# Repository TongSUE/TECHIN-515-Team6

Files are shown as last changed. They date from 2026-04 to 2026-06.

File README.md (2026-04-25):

# AuraSync — Context-Aware Scent Diffuser

**AuraSync** automatically detects bathroom context (shower, odor, presence) via sensor fusion and triggers a fragrance diffuser at the right moment — no manual input required.

**Devlog:** [tongsue.github.io/TECHIN-515-Team6](https://tongsue.github.io/TECHIN-515-Team6/)  
**Course:** TECHIN 515 Hardware-Software Lab II, UW, Spring 2026  
**Team:** Yutong Luo (@TongSUE) · Lucia Shen (@xtshen777)

---

## Hardware

| Component | Role |
|---|---|
| Seeed XIAO ESP32-S3 | MCU — dual-core, 8 MB PSRAM, native I2S |
| Adafruit SPH0645LM4H | I2S MEMS microphone — voice recognition |
| HC-SR501 PIR | Presence detection — triggers actuation |
| Adafruit BME680 | Temp / humidity / pressure / VOC (I2C 0x77) |
| Ultrasonic atomizer + 2N2222 NPN | Fragrance mist actuation |
| MT3608 boost converter + 3.7 V LiPo | Power supply |

### Pin Assignments

| Function | Arduino Pin | GPIO |
|---|---|---|
| I2C SDA (BME680) | D4 | 5 |
| I2C SCL (BME680) | D5 | 6 |
| I2S BCLK (SPH0645) | D8 | 7 |
| I2S LRCLK (SPH0645) | D9 | 8 |
| I2S DOUT (SPH0645) | D10 | 9 |
| PIR signal (HC-SR501) | — | 4 |
| Atomizer MOSFET gate | — | 5 |
| Status LED | D0 | 21 |

> SPH0645: SEL pin → GND (left channel). Data in bits [31:14] of 32-bit I2S frame.  
> BME680: use `Wire.begin()` with no arguments — the framework maps D4/D5 by default.

---

## Repository Layout

```
Web/                          ← git root (this repo)
├── Code/
│   ├── AuraSync/             ← main firmware (two-layer state machine)
│   │   ├── AuraSync.ino
│   │   ├── partitions.csv    ← custom flash layout (app0 3.7 MB + model SPIFFS 4.25 MB)
│   │   └── secrets.h.example ← copy to secrets.h and fill in credentials
│   ├── VoiceTest/            ← ESP-SR voice recognition prototype
│   │   └── voice_monitor.html← Web Serial browser monitor
│   ├── FirebaseTest/         ← VoiceTest + Firebase Realtime Database
│   ├── MicTest/              ← SPH0645 bring-up / VAD test
│   ├── PIRTest/              ← PIR motion-triggered spray controller
│   └── PsramTest/            ← PSRAM validation
├── KiCAD/AuraSync_v1/        ← schematic + PCB layout (KiCAD 9)
├── monitor/
│   ├── voice_monitor.py      ← real-time serial monitor (USB, Streamlit)
│   ├── firebase_dashboard.py ← cloud dashboard (reads Firebase, no USB needed)
│   └── requirements.txt
├── web-devlog/               ← React + Vite devlog site
└── README.md
```

---

## Flashing AuraSync (Main Firmware)

1. Copy `Code/AuraSync/secrets.h.example` → `Code/AuraSync/secrets.h` and fill in your WiFi + Firebase credentials
2. Open `Code/AuraSync/AuraSync.ino` in Arduino IDE
3. **Tools → Board:** Seeed XIAO ESP32-S3
4. **Tools → PSRAM:** OPI PSRAM
5. **Tools → Partition Scheme:** Huge APP (3MB No OTA / 1MB SPIFFS)
6. Run `Code/VoiceTest/flash_model.ps1` **once** to write ESP-SR models to flash
7. Upload `AuraSync.ino`
8. Say **"Aura"** to open the 7-second command window, then **"Spray"** or **"Stop"**; PIR presence for ≥ 3 s also triggers spray

---

## Running the Serial Voice Monitor

Streams live audio level and recognised commands from the ESP32-S3 over USB serial.

**Requirements:** Python 3.9+, ESP32-S3 flashed with `VoiceTest.ino` or `AuraSync.ino`, Arduino IDE serial monitor **closed**.

```bash
cd monitor
pip install -r requirements.txt
streamlit run voice_monitor.py
```

Opens at `http://localhost:8501`. The app auto-detects the COM port — no configuration needed.

---

## Running the Firebase Cloud Dashboard

Reads spray events from Firebase Realtime Database — no USB connection required.

```bash
cd monitor
pip install -r requirements.txt
streamlit run firebase_dashboard.py
```

Opens at `http://localhost:8502`. Supports dark/light mode toggle; auto-refreshes every 5 seconds.

---

## Flashing VoiceTest (Voice Recognition Prototype)

1. Open `Code/VoiceTest/VoiceTest.ino` in Arduino IDE
2. **Tools → Board:** Seeed XIAO ESP32-S3
3. **Tools → PSRAM:** OPI PSRAM
4. **Tools → Partition Scheme:** Huge APP (3MB No OTA / 1MB SPIFFS)
5. Run `Code/VoiceTest/flash_model.ps1` **once** to write ESP-SR models to flash
6. Upload `VoiceTest.ino`
7. Say **"Aura"** to open the 7-second command window, then **"Spray"** or **"Stop"**

---

## Firmware Overview

### `Code/AuraSync/AuraSync.ino` — Main firmware (Week 4+)

Two-layer state machine, non-blocking (`millis()` only, no `delay()` in main loop):

**Layer 1 — System Mode** (PIR-driven presence):
```
MODE_SLEEP  ──PIR detected──▶  MODE_AWAKE
MODE_AWAKE  ──60 s no PIR──▶  MODE_SLEEP
```

**Layer 2 — Spray State** (shared absolute cooldown):
```
SPRAY_IDLE → SPRAY_SPRAYING (5 s) → SPRAY_COOLDOWN (20 s test / 3 min prod) → SPRAY_IDLE
```

Four-priority trigger model: P1 voice/app (bypasses cooldown, works in SLEEP) → P2 extreme VOC < 10 kΩ (works in SLEEP, queues during cooldown) → P3 PIR + VOC inflection (AWAKE + IDLE only).

FreeRTOS dual-core: I2S + ESP-SR on Core 1 at max priority; PIR, state machine, Firebase, BME680 on Core 0. Power saving: `WiFi.setSleep(WIFI_PS_MAX_MODEM)` + Core 0 throttle in SLEEP mode (~30 mA idle from 2000 mAh LiPo ≈ 60–70 h).

### `Code/VoiceTest/VoiceTest.ino` — Voice recognition prototype

ESP-SR AFE + MultiNet v7 on FreeRTOS Core 1. Wake-word state machine:

```
IDLE → (say "Aura") → LISTENING [7 s] → (say "Spray"/"Stop") → IDLE
```

### `Code/FirebaseTest/FirebaseTest.ino` — Voice + Firebase

Extends VoiceTest: SR task (Core 1) → FreeRTOS queue → `loop()` (Core 0) → `Firebase.RTDB.pushJSON()`. Auth via database-secret legacy token; NTP time sync at boot.

---

## Devlog Site

Built with React 19 + Vite. Auto-deployed to GitHub Pages.

```bash
cd web-devlog
npm install
npm run dev       # local preview
npm run build     # production build
```

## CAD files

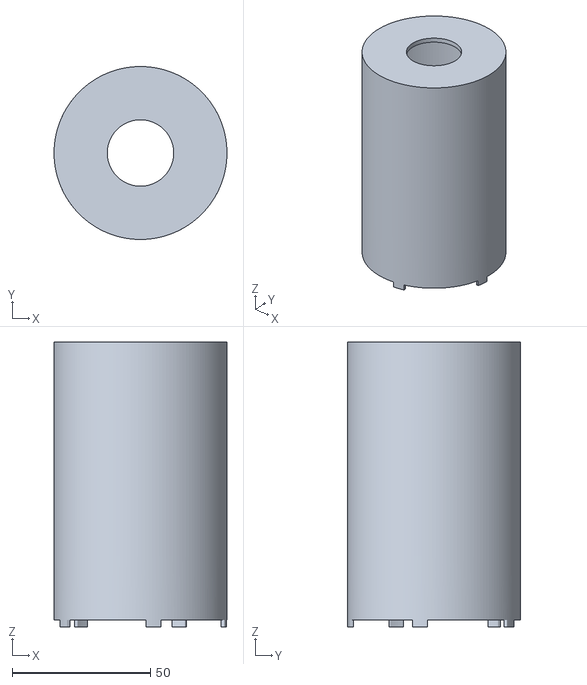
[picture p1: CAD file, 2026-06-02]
3D Model/inner body.stl
62.5 x 62.5 x 103.0

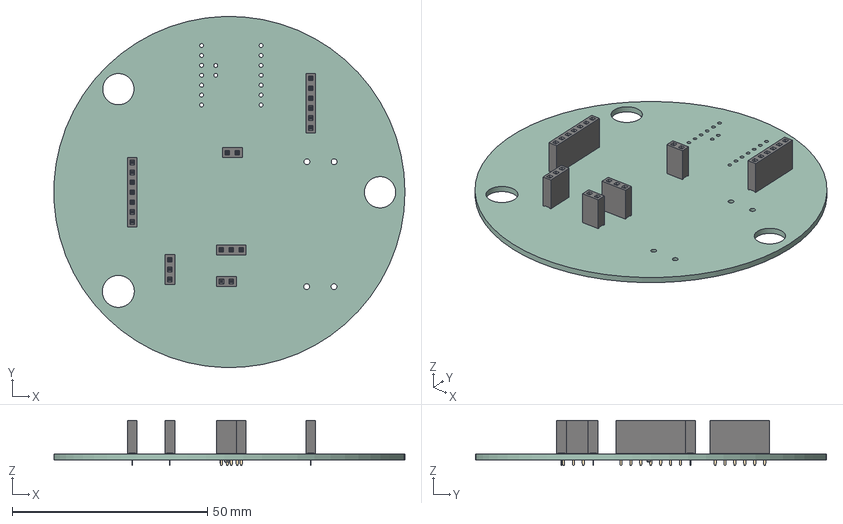
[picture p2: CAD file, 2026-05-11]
KiCAD/AuraSync_v2/AuraSync_v2.step
89.9 x 90.0 x 11.6 mm
PinSocket_1x02_P2.54mm_Vertical x 2
PinSocket_1x07_P2.54mm_Vertical
PinSocket_1x03_P2.54mm_Vertical x 2
PinSocket_1x06_P2.54mm_Vertical
R_0603_1608Metric
AuraSync_v2_PCB

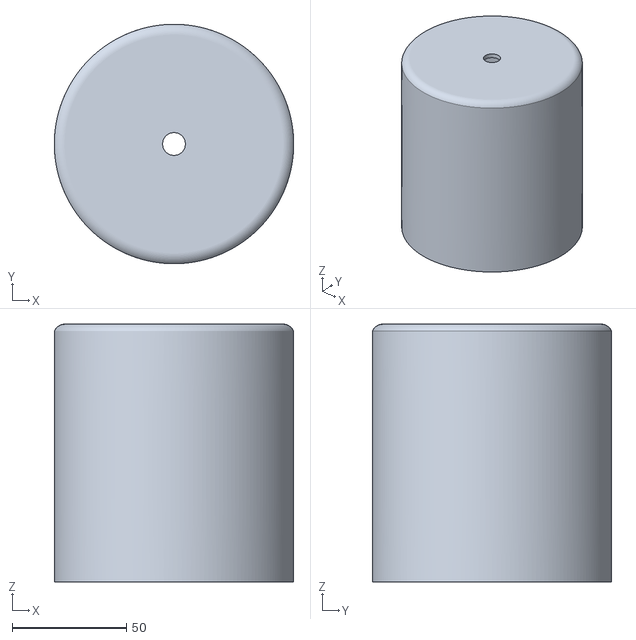
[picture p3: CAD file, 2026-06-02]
3D Model/upper body.stl
105.0 x 105.0 x 113.2

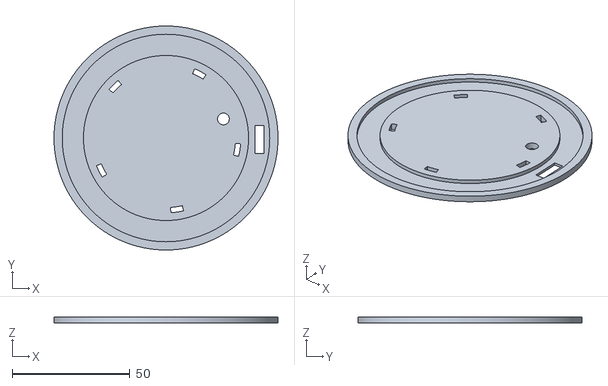
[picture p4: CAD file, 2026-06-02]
3D Model/platform stand.stl
95.0 x 95.0 x 2.50

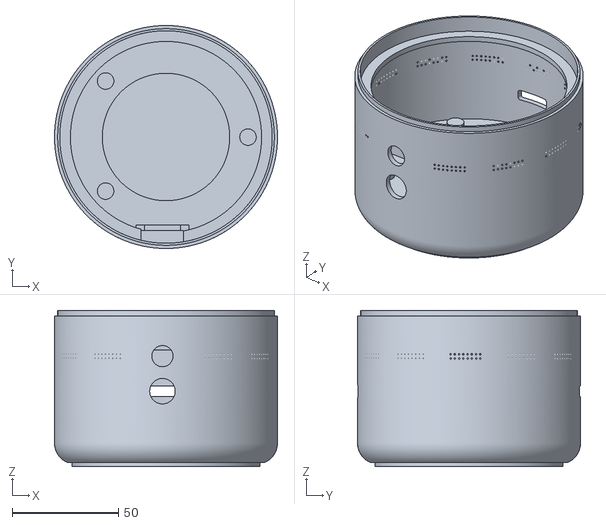
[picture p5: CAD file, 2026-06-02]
3D Model/lower body.stl
105.0 x 105.0 x 73.5

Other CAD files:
3D Model/aurasync.f3z

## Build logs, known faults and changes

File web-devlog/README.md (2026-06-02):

# AuraSync — TECHIN 515 Team 6

**AuraSync** is a context-aware bathroom scent diffuser built for MSTI Hardware–Software Lab II (TECHIN 515), Spring 2026. It senses shower, odor, and presence events using on-device sensor fusion and ML, then autonomously actuates an ultrasonic atomizer to dispense fragrance at the right moment.

Live devlog: [https://tongsue.github.io/TECHIN-515-Team6/](https://tongsue.github.io/TECHIN-515-Team6/)

---

## Team

| Member | GitHub | Focus |
|---|---|---|
| Yutong Luo | [@TongSUE](https://github.com/TongSUE) | Firmware · App · PCB · Devlog site |
| Lucia Shen | [@xtshen777](https://github.com/xtshen777) | Hardware · ML · CAD · Firmware |

---

## System Overview

### Hardware

| Component | Role |
|---|---|
| XIAO ESP32-S3 | Dual-core LX7 MCU, 8 MB flash, PSRAM |
| BME680 | Temperature / humidity / pressure / VOC gas resistance |
| INMP441 | I²S MEMS microphone (right channel, 16 kHz) |
| WS2812B × 24 | State-reactive LED ring (FastLED, GPIO3) |
| Ultrasonic atomizer | N-channel MOSFET drive on GPIO4 |
| Custom PCB | Circular R = 45 mm, JST connectors, MT3608 boost |
| LiPo 3.7 V | Battery via MT3608 → 5 V supply rail |

### Firmware

Built with **PlatformIO** (pioarduino, ESP-IDF 5.x). Key subsystems:

- **Two-layer state machine** — outer SLEEP/AWAKE, inner IDLE/SPRAYING/COOLDOWN
- **BSEC2** — self-calibrating IAQ index from BME680 via Bosch library
- **ESP-SR MultiNet7** — on-device wake-word + command recognition (`aura` / `spray` / `release` / `stop` / `fragrance`)
- **On-device ML** — IAQ MLP + Shower 1D-CNN infer from a 120-entry ring buffer (no cloud step)
- **Firebase RTDB** — bidirectional sync: app → ESP32 commands; ESP32 → app sensor data / status
- **DEMO\_MODE** — fast 3 s sampling, 30 s warmup, relaxed thresholds for classroom demos

### Five Trigger Paths

| # | Trigger | Mechanism |
|---|---|---|
| 1 | Voice | MultiNet7 detects "spray" or "release" keyword |
| 2 | App | Firebase command executed from any device state |
| 3 | IAQ Poor | On-device MLP classifies air quality as Poor |
| 4 | Shower CNN | 1D-CNN probability exceeds 0.65 |
| 5 | VOC + PIR | VOC inflection detected → PIR fires within 60 s |

Paths 3–5 are gated by the `autoSprayEnabled` flag from the app.

### LED Ring States

| State | Animation |
|---|---|
| Sleep | Slow blue breathing |
| IAQ Good / Moderate / Poor | Green / yellow / orange breathing |
| Spraying | White rotating chase |
| Cooldown | Cyan fade-out |
| Voice window | Purple double-flash |

### Mobile App

React Native (Expo SDK 54) + Firebase JS SDK 10. Features: live Air Quality card, spray history log, Auto-Spray toggle, reservoir tracker with reset, dual Firebase / ESP32 online status indicator.

### ML Pipeline

| Model | Input | Output | Performance |
|---|---|---|---|
| IAQ MLP (64→32→3) | 10 BSEC2 features | Good / Moderate / Poor | CV Macro F1 variance ±0.012 |
| Shower 1D-CNN | 30×6 normalised window | Shower probability | Val F1 0.902, AUC 0.94 |

Trained on 16 927 labelled bathroom readings; weights exported as C float arrays and inferred entirely on-chip.

---

## Devlog Site

Built with **React 19 + Vite 8 + Tailwind CSS 4**. Each week is a Markdown file with YAML front matter. Supports English / Chinese locale switching.

```
web-devlog/
├── public/images/devlog/       # Photos and figures
├── src/
│   ├── components/             # React UI components
│   ├── content/devlog/         # week-NN.md / week-NN.zh.md
│   ├── pages/                  # DevlogWeekPage, HomePage
│   └── i18n/strings.js         # EN/ZH UI strings + homepage credits
└── .github/workflows/          # GitHub Pages deploy
```

### Local development

```bash
cd web-devlog
npm install
npm run dev        # http://localhost:5173
```

Deployed automatically to GitHub Pages on every push to `main`.

---

MSTI Hardware–Software Lab II · Team 6 · Spring 2026

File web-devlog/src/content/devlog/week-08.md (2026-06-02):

---
week: 8
date: "May 19 - May 25, 2026"
title: "Enclosure Finishing, PCB Bring-up, LED Ring & Full Assembly"
status: "In Progress"
show_next_steps: true
summary: >
  The final build sprint. Yutong SLA-printed and wet-sanded the lower base
  (60 → 1000 grit, water-cooled), then trimmed, drilled, and accidentally
  cracked the clear resin lid — the team chose same-resin repair over recasting;
  Lucia prepared a fresh mold as backup; the repair finished cleaner than
  expected. The custom PCB arrived: Yutong soldered all components and wired
  the 24-LED WS2812B ring. Lucia integrated five state-reactive LED animations,
  migrated the build to PlatformIO (ESP-IDF 5.x), and tuned voice recognition
  — adding "Release" as a second trigger word after "Spray" proved unreliable
  in noisy environments. Final assembly confirmed all five trigger paths
  working end-to-end.
credits:
  - name: Lucia
    initials: L
    tags:
      - LED Firmware
      - Voice Tuning
      - Resin Lid Re-mold (backup)
      - Full Assembly
      - Final Presentation Slides
  - name: Yutong
    initials: Y
    tags:
      - PCB Soldering
      - Enclosure Finishing
      - Resin Lid Repair
      - Full Assembly
      - Devlog
prior_week_progress:
  sand-cover: true
  print-base: true
  full-assembly: true
  pcb-soldering: true
  backup-video: "partial"
planned_next:
  - id: backup-video
    label: Record Backup Demo Video
    description: "Record a complete run-through of all five trigger paths as a fallback in case the live demo has connectivity or environmental issues."
  - id: final-demo
    label: Final Project Demo
    description: "Present AuraSync at the final demo session — device, app, and Firebase all operational; all five trigger paths ready."
---

## Executive Summary

Four tracks this week brought the project to completion.

- **Enclosure** — Both halves finished. Yutong SLA-printed and wet-sanded the lower base (60 → 1000 grit, water-cooled) with Kevin's guidance. The resin upper lid was trimmed with a band saw, then drilled for the spray nozzle — the resin cracked. After consulting Kevin, the team chose same-resin repair over recasting; Lucia prepared a backup mold in parallel. The repair was unexpectedly clean; both halves were re-sanded together to a uniform frosted finish.
- **PCB & Electronics** — The custom PCB arrived. Yutong soldered all breakout connectors, the atomizer MOSFET, MT3608, and WS2812B ring leads. Several debugging passes cleared short circuits before bring-up was clean.
- **Firmware** — Lucia integrated five state-reactive WS2812B animations and migrated the build to PlatformIO (ESP-IDF 5.x). Voice recognition was tuned after "Spray" proved unreliable in ambient noise — "Release" was added as a second trigger word.
- **Full Assembly** — All components seated in the enclosure. All five trigger paths verified end-to-end. The app → Firebase → ESP32 pipeline and LED ring are both operational.

## 1. Enclosure — Final Finishing

### Lower Base — SLA Print & Sanding

With the SLA printer repaired, Yutong printed the lower base resin with Kevin's guidance. Post-print finishing:

1. Remove support structures
2. UV post-cure (secondary hardening pass)
3. Wet-sand: 60 → 120 → 240 → 400 → 600 → 1000 grit

> **Wet-sanding tip:** Keeping the sandpaper dipped in water throughout each grit stage dissipates heat — preventing the resin from micro-melting and clogging the abrasive — and eliminates resin dust becoming airborne. The water turns visibly cloudy as it lifts the material instead.

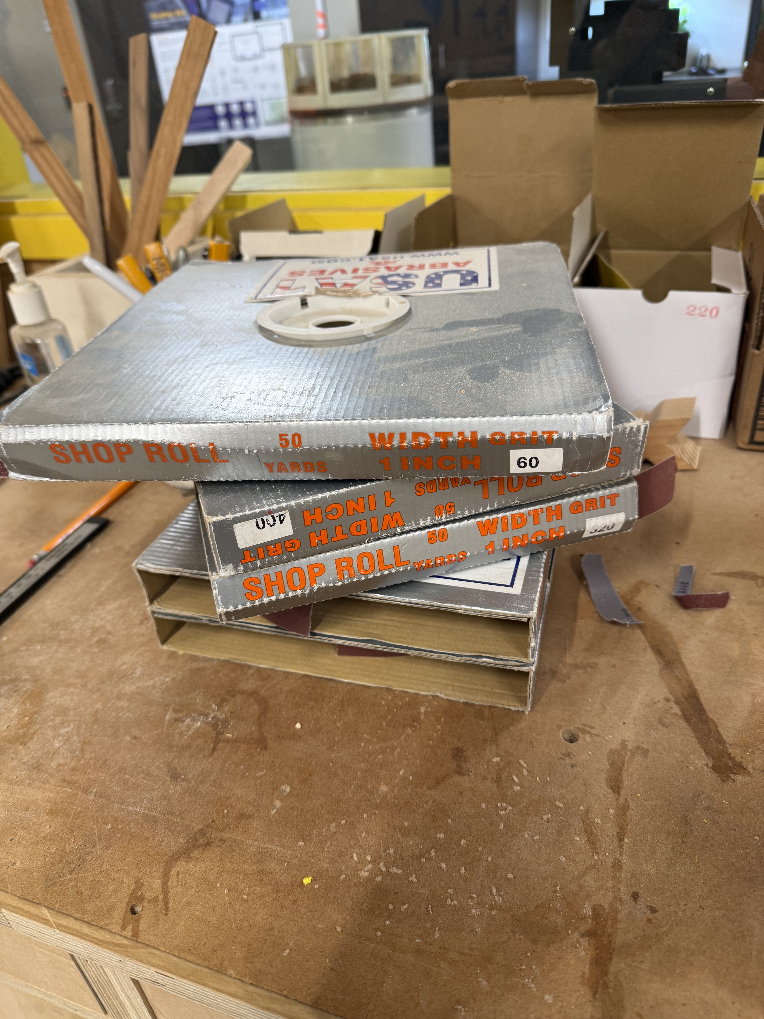
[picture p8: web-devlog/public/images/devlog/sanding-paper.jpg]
Wet sanding the lower base — sandpaper dipped in water at each grit stage Wet sanding — water keeps the paper clear and prevents heat build-up


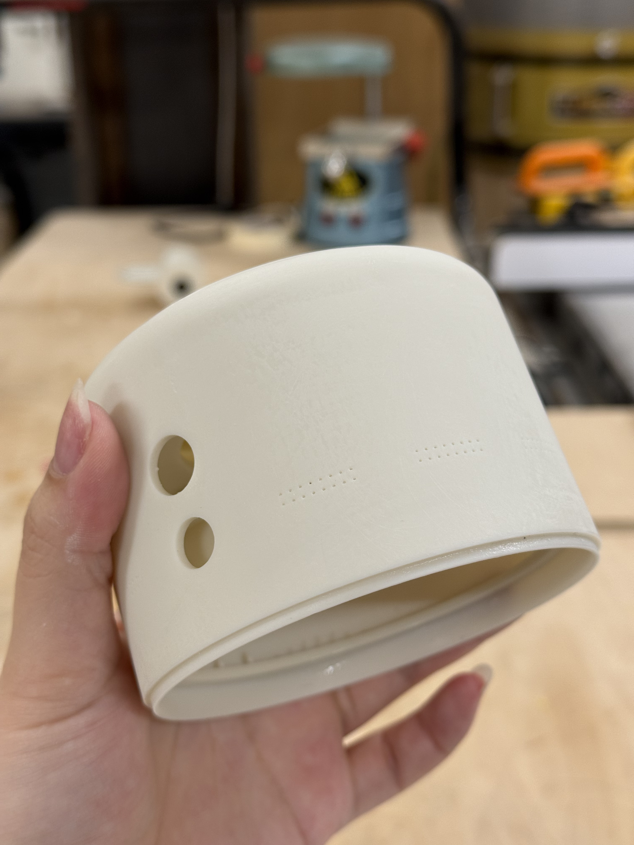
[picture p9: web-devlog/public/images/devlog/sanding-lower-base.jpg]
Finished lower base after SLA printing and wet sanding to 1000 grit Finished lower base — smooth resin surface ready for assembly


### Transparent Upper Lid — Trim, Drill & Repair

The cast resin lid needed two finishing steps: trim excess flash from the perimeter and drill the spray nozzle opening at the apex.

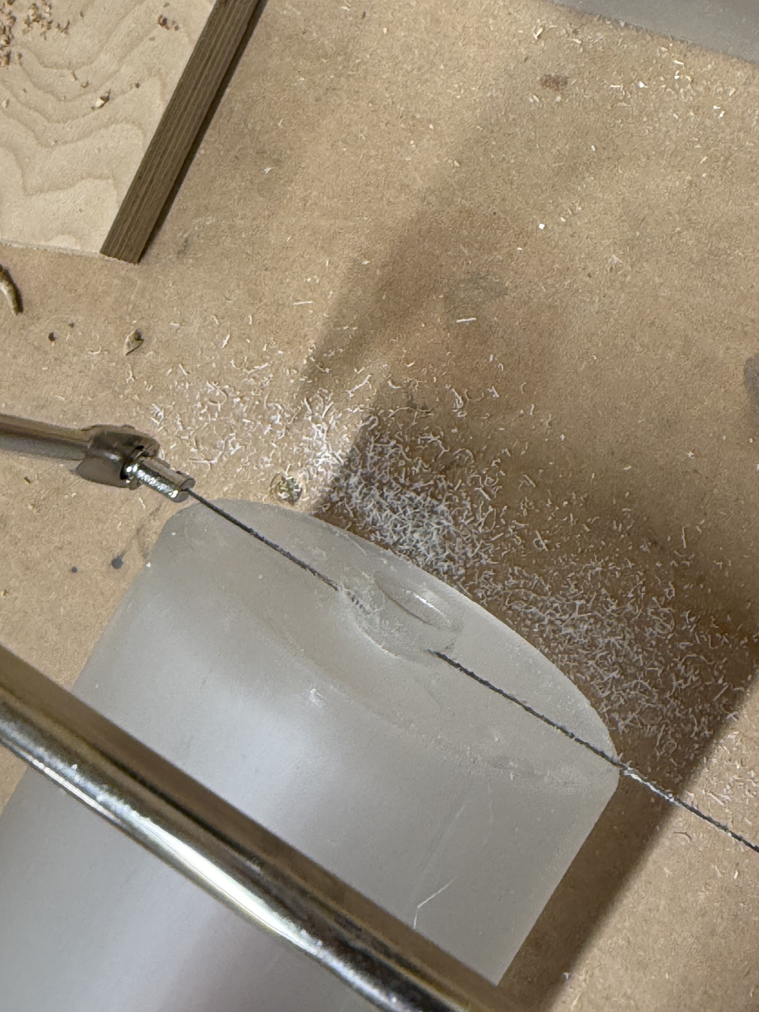
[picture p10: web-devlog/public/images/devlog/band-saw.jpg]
Trimming excess resin flash from the lid perimeter with a band saw Band saw trim — removing excess flash before drilling the nozzle hole


After trimming, the spray hole was drilled at the top centre. When the drill broke through, the resin cracked radially outward from the hole.

Kevin was consulted. Three options were considered:

| Option | Pros | Cons |
|---|---|---|
| Recast | Guaranteed clean result | 48+ h cure; lose the finished piece |
| UV glue repair | Fast (minutes) | Different material; may leave a visible seam |
| Same-resin repair | Material match; strong, near-invisible bond | 24 h cure; cosmetic result uncertain |

> **Why same-resin?** Using the identical material means the fill bonds chemically with the surrounding piece rather than just adhering to the surface — the seam becomes structurally continuous. After sanding, the colour, translucency, and surface texture match the original almost perfectly. In parallel, Lucia re-modelled and prepared a fresh silicone mold as a backup in case the repair failed — it turned out not to be needed.

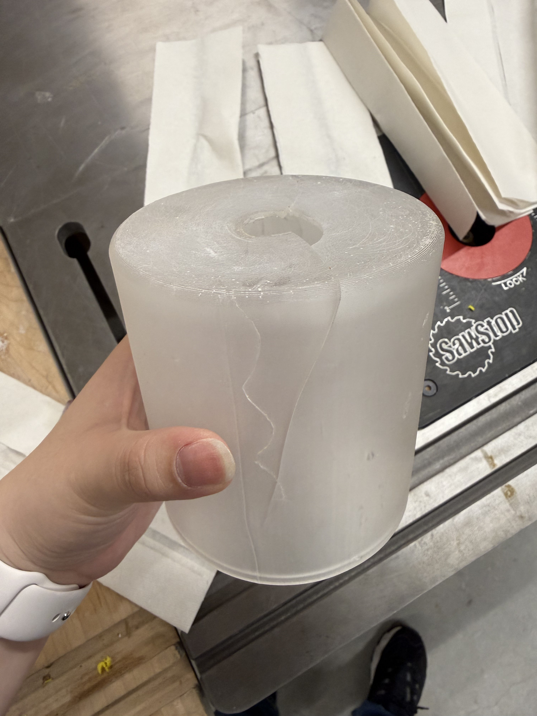
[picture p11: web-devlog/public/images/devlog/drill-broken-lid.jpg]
Resin upper lid with radial cracks from the drilled spray nozzle opening Drill-through crack — resin cracked radially from the nozzle hole


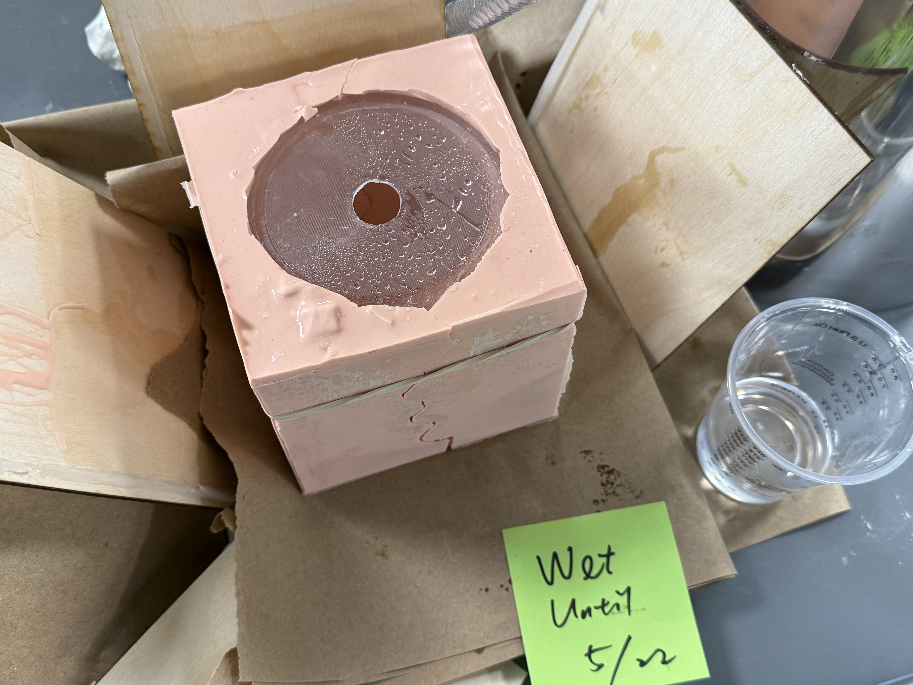
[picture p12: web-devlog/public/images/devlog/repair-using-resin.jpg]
Same-resin repair — liquid resin worked into cracks before 24 h cure Same-resin repair — liquid resin fills the cracks; 24 h cure


After curing, Lucia and Yutong re-sanded the lid together.

> The repair was cleaner than the team expected — after re-sanding, the crack lines are nearly invisible and the frosted finish is consistent across the whole surface.

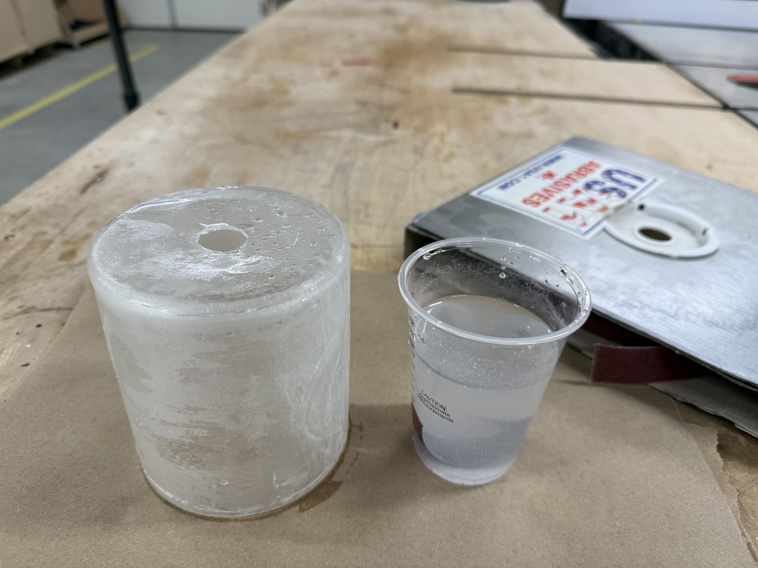
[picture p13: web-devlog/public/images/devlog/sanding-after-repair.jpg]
Re-sanding the repaired lid — Lucia and Yutong finishing together Post-repair sanding — crack lines nearly invisible after re-sand


## 2. PCB & Electronics

The custom PCB arrived this week. Yutong soldered all components onto the board:

- JST connector headers — ESP32-S3, BME680, PIR, INMP441
- MOSFET + gate resistor for the atomizer drive circuit
- MT3608 boost converter pads
- 24-LED WS2812B ring lead wires to GPIO3 (D2)

Multiple debugging passes identified and cleared short circuits before the board passed bring-up cleanly.

## 3. Firmware — LED Ring & Voice

### WS2812B LED Ring

Lucia integrated a 24-LED WS2812B ring (FastLED 3.9.0, GPIO3) with five state-reactive animations that give AuraSync a clear visual language for every state:

| Device state | Animation |
|---|---|
| Sleep | Slow blue breathing |
| IAQ Good / Moderate / Poor | Green / yellow / orange breathing |
| Spraying | White rotating chase (3–4 pixels, 30 ms/step) |
| Cooldown | Cyan fade-out |
| Voice trigger window | Purple double-flash |

Frame rate capped at ~60 fps via `millis()` delta (16 ms per tick).

### PlatformIO Migration

The build was migrated from Arduino IDE (ESP-IDF 4.x) to **PlatformIO** (pioarduino, ESP-IDF 5.x). FastLED 3.9.0 is now pinned, builds are reproducible, and compiler diagnostics are much cleaner.

### Voice Command Tuning

After full assembly, voice recognition was tested in real conditions. The results were mixed:

- **"Aura"** (wake) and **"Stop"** (cancel) — reliable
- **"Spray"** — consistently missed in ambient noise

> **Why "Spray" fails and "Release" works:** "Spray" opens with a sibilant /spr/ cluster — a high-frequency blend that the acoustic cavity significantly attenuates. "Release" has a liquid-consonant onset and an open vowel, making it far more robust in a noisy room. Both words now map to the same spray action; the system effectively gained a more reliable trigger word for free.

Fix: **"Release"** was added as a second trigger word with the MultiNet7 threshold at `0.45f`. Active voice commands: `aura` / `spray` / `fragrance` / `release` / `stop`

## 4. Full Assembly & Integration

All components were seated into the assembled enclosure. All five trigger paths confirmed to fire correctly:

1. **Voice** — "Aura" wake + "Release" / "Spray" triggers spray via priority queue
2. **App** — Firebase command received and executed from any state, including SLEEP
3. **IAQ Poor** — on-device MLP classifies air quality as Poor; triggers spray (gated by `autoSprayEnabled`)
4. **Shower CNN** — 1D-CNN probability exceeds threshold; transitions to SPRAYING (gated by `autoSprayEnabled`)
5. **VOC inflection + PIR (P3)** — latch: inflection detected → PIR fires within 60 s → spray (gated by `autoSprayEnabled`)

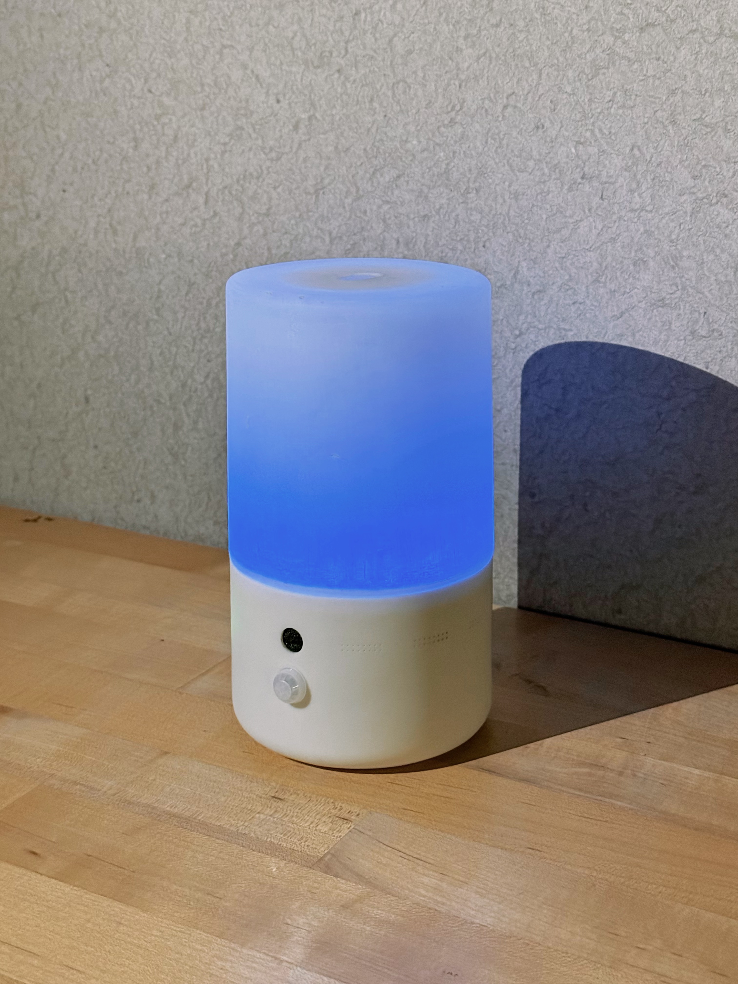
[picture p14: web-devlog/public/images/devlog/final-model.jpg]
AuraSync fully assembled — transparent frosted upper lid over resin lower base, all components seated Final assembly — both halves closed, all components inside


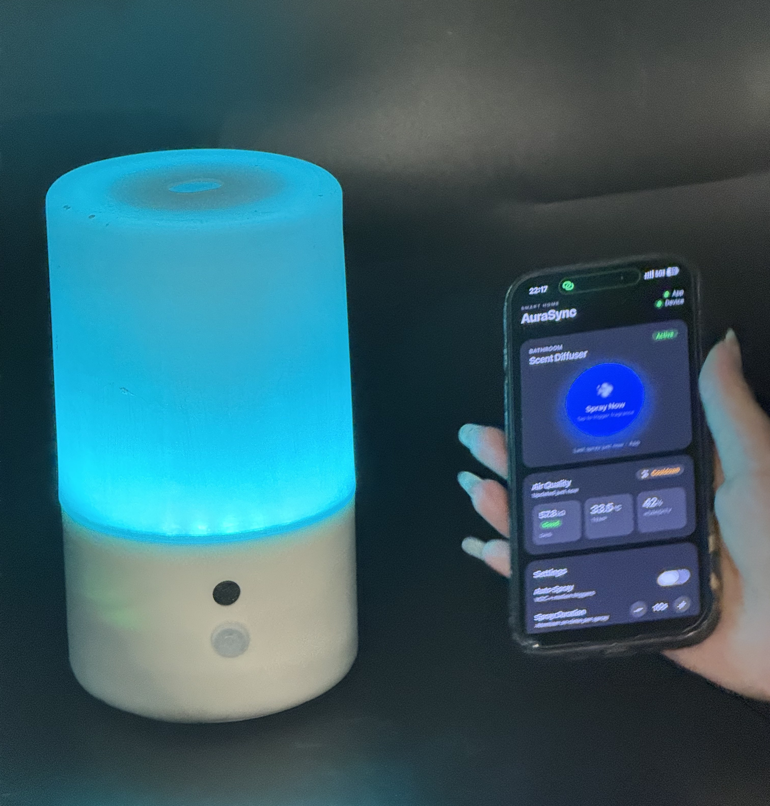
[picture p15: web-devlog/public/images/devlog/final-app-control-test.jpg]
App trigger test — spray command sent via Firebase, ESP32 responds in real time App trigger — Firebase → ESP32 in ~1 s


### Demo Footage

Raw footage of all five trigger paths was captured during integration testing this week. The clips are not yet edited or polished enough for a formal submission — a proper re-record with clean takes and narration is planned for next week.

## Next Steps

| Done | Task | Description |
|:-:|---|---|
| <input type="checkbox" /> | **Record Backup Demo Video** | Re-record all five trigger paths with clean takes; edit into a submission-ready demo video. |
| <input type="checkbox" /> | **Final Project Demo** | Present AuraSync — device, app, and Firebase all operational; all five trigger paths ready. |

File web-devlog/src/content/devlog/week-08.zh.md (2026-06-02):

---
week: 8
date: "2026年5月19日 - 5月25日"
title: "外壳收尾、PCB 焊接、灯带固件与整机组装"
status: "In Progress"
show_next_steps: true
summary: >
  最后的冲刺。Yutong 在 Kevin 的帮助下 SLA 打印了下底座并湿磨至
  1000 目；随后用条锯修整、钻孔打开雾化口——树脂裂开了。团队咨询
  Kevin 后选择用同款树脂填补裂缝，Lucia 同步重新建模做了备用翻模模具，
  最终修补效果出乎意料地好。定制 PCB 到货，Yutong 完成了全部元件及
  WS2812B 灯带的焊接。Lucia 集成了五种状态响应式灯带动画，将构建
  系统迁移至 PlatformIO（ESP-IDF 5.x），并对语音识别进行了调优——
  新增"Release"作为"Spray"的替代触发词。整机组装后五条触发路径
  全部验证通过。
credits:
  - name: Lucia
    initials: L
    tags:
      - LED 灯带固件
      - 语音调优
      - 树脂上盖翻模（备用）
      - 整机组装
      - 最终演示幻灯片
  - name: Yutong
    initials: Y
    tags:
      - PCB 焊接
      - 外壳收尾
      - 树脂上盖修补
      - 整机组装
      - 开发日志
prior_week_progress:
  sand-cover: true
  print-base: true
  full-assembly: true
  pcb-soldering: true
  backup-video: "partial"
planned_next:
  - id: backup-video
    label: 录制备用演示视频
    description: "重新录制五条触发路径的完整演示，剪辑为正式提交版本，以备现场演示出现网络或环境问题时使用。"
  - id: final-demo
    label: 最终演示
    description: "在结课演示中展示 AuraSync——设备、应用与 Firebase 全部就绪，五条触发路径均可演示。"
---

## 执行摘要

本周四条主线，项目完成收官。

- **外壳** — 上下两半全部完工。Yutong 在 Kevin 指导下打印并湿磨好了下底座（60 → 1000 目，水冷打磨）；透明上盖用条锯裁边后钻雾化口，钻穿时树脂从孔缘向外放射状开裂。咨询 Kevin 后选择同款树脂填补，Lucia 同步重新建模备用翻模模具。修补效果惊人地干净，两人共同打磨后裂缝几乎不可见。
- **PCB 与电路** — 定制 PCB 到货。Yutong 完成了所有元件及 WS2812B 灯带的焊接，经多轮调试排除短路后成功上电。
- **固件** — Lucia 集成了五种状态响应式 WS2812B 灯带动画，将构建系统迁移至 PlatformIO（ESP-IDF 5.x）。在真实环境中测试后发现"Spray"识别率较差，新增"Release"作为第二触发词，识别效果显著改善。
- **整机组装** — 全部组件装入外壳，五条触发路径逐一验证通过。应用 → Firebase → ESP32 喷雾链路稳定可靠，灯带状态反馈清晰。

## 1. 外壳——最终收尾

### 下底座——SLA 打印与打磨

打印机修好后，Yutong 在 Kevin 的指导下完成了下底座树脂打印。打印后处理流程：

1. 去除支撑结构
2. UV 二次固化
3. 湿磨：60 → 120 → 240 → 400 → 600 → 1000 目

> **湿磨技巧：** 砂纸全程浸水，既能散热——防止树脂因摩擦微熔堵塞砂粒——又能将粉尘锁在水中，避免扬尘。水变浑浊正是材料被带走的信号，比干磨效率更高。

湿磨下底座——砂纸在每个目数阶段均浸水打磨 湿磨——水分保持砂纸清洁，防止发热

打磨完成的下底座——SLA 打印、UV 固化并湿磨至 1000 目 完成后的下底座——树脂表面光洁，可以装配

### 透明上盖——裁切、钻孔与修补

翻模完成的树脂上盖需要两步收尾：用条锯裁去多余边缘，再在顶部钻出雾化口。

用条锯裁切上盖多余边缘 条锯修边——裁去多余树脂后再钻孔

裁边完成后，在顶部中心钻雾化口。钻头钻穿瞬间，树脂从孔缘向外放射状开裂。

咨询 Kevin 后，团队综合评估了三种方案：

| 方案 | 优点 | 缺点 |
|---|---|---|
| 重新翻模 | 效果有保障 | 固化 48 小时以上；成品报废 |
| UV 胶修补 | 快速（数分钟） | 材料不同，可能留下可见痕迹 |
| 同款树脂修补 | 材质匹配，粘合牢固，几乎不留痕 | 需固化 24 小时；外观效果存在不确定性 |

> **为什么选同款树脂？** 使用相同材料填补，树脂与周围结构形成化学键合而非单纯的表面粘附——接缝从结构上变为一体。打磨后颜色、透明度与表面质感几乎与原件完全一致。与此同时，Lucia 重新建模、制作了一套备用硅胶模具，以备修补失败时重新翻模——最终没用上。

透明树脂上盖——钻孔导致从孔缘向外放射状开裂 钻孔裂缝——树脂脆性较大，钻穿瞬间向外开裂

同款树脂修补——将液态树脂渗入裂缝，固化 24 小时 树脂修补中——液态树脂填充裂缝，固化 24 小时

固化后，Lucia 与 Yutong 共同打磨。

> 修补效果出乎意料地好——重新打磨后，裂缝几乎不可见，磨砂质感均匀覆盖整个表面。

修补固化后重新打磨——Lucia 与 Yutong 共同完成收尾 修补后打磨——裂缝几乎消失，磨砂质感均匀

## 2. PCB 与电路

定制 PCB 本周到货。Yutong 将全部元件焊接上板：

- JST 接插件——ESP32-S3、BME680、PIR、INMP441
- 雾化片 MOSFET 驱动电路（含栅极电阻）
- MT3608 升压转换器焊盘
- 24 颗 WS2812B 灯带引线接至 GPIO3（D2）

经过多轮调试排除短路故障后，电路板成功通电上电。

## 3. 固件——灯带与语音

### WS2812B 灯带集成

Lucia 集成了 24 颗 WS2812B 灯带（FastLED 3.9.0，GPIO3），实现五种状态响应式动画，为 AuraSync 每个状态提供清晰的视觉语言：

| 设备状态 | 动画效果 |
|---|---|
| 休眠 | 蓝色缓慢呼吸 |
| IAQ 好 / 中 / 差 | 绿 / 黄 / 橙色呼吸（随 IAQ 等级变化） |
| 喷雾中 | 白色旋转追光（3–4 颗亮点，30 ms/步） |
| 冷却中 | 青色渐隐 |
| 语音触发窗口 | 紫色双闪 |

帧率上限约 60 fps，通过 `millis()` 增量计时（每帧 16 ms）控制。

### PlatformIO 迁移

固件构建系统从 Arduino IDE（IDF 4.x）迁移至 **PlatformIO**（pioarduino，ESP-IDF 5.x）。FastLED 3.9.0 版本现已锁定，构建可复现，编译器诊断信息也更为清晰。

### 语音指令调优

整机组装完成后，在真实环境中测试了语音识别，结果好坏参半：

- **"Aura"**（唤醒词）和 **"Stop"**（取消）——识别稳定
- **"Spray"**——在环境噪音中频繁漏识

> **为什么"Spray"容易漏识，"Release"不会？** "Spray"以辅音簇 /spr/ 开头——这是一组高频摩擦音，在 AuraSync 的声学腔体中被大幅衰减。而"Release"以流音辅音开头，接开口元音，在嘈杂环境中鲁棒性强得多。两个词现在映射相同的喷雾动作，相当于免费获得了一个更可靠的触发词。

修复方案：新增 **"Release"** 作为第二触发词，MultiNet7 置信度阈值设为 `0.45f`。当前有效语音指令：`aura` / `spray` / `fragrance` / `release` / `stop`

## 4. 整机组装与集成

全部组件装入组合后的外壳。五条触发路径逐一确认正常触发：

1. **语音** — "Aura" 唤醒 + "Release"/"Spray" 经优先级队列路由触发喷雾
2. **应用** — Firebase 指令可从任意状态（含 SLEEP）接收并执行
3. **IAQ Poor** — 端侧 MLP 将空气质量分类为 Poor，触发喷雾（受 `autoSprayEnabled` 控制）
4. **淋浴 CNN** — 1D-CNN 概率超过阈值，切换至 SPRAYING（受 `autoSprayEnabled` 控制）
5. **VOC 拐点 + PIR（P3）** — 锁存机制：检测到拐点 → PIR 在 60 秒内触发 → 喷雾（受 `autoSprayEnabled` 控制）

AuraSync 整机组装完成——透明磨砂上盖与树脂下底座合拢，全部组件就位 整机组装完成——两半合拢，内部组件全部就位

应用触发测试——通过 Firebase 发送喷雾指令，ESP32 实时响应 应用触发——Firebase → ESP32，响应约 1 秒

### 演示视频

本周在集成测试中拍摄了五条触发路径的原始素材。目前这些视频片段尚未剪辑，也不够正式——计划下周进行正式补录与剪辑，制作一段完整的演示视频。

## 下一步计划

| 完成 | 任务 | 说明 |
|:-:|---|---|
| <input type="checkbox" /> | **录制备用演示视频** | 重新录制五条触发路径并剪辑为正式提交版本，以备现场连接问题时使用。 |
| <input type="checkbox" /> | **最终演示** | 在结课演示中展示 AuraSync——设备、应用与 Firebase 全部就绪，五条触发路径均可演示。 |

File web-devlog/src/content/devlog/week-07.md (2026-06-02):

---
week: 7
date: "May 12 - May 18, 2026"
title: "AuraSync v4, Open House Demo, App UI Polish & Enclosure Casting"
status: "Completed"
show_next_steps: true
summary: >
  Four tracks this week. Lucia upgraded the firmware to AuraSync v4: added
  DEMO_MODE (3 s sampling, 30 s warmup), rewrote the P3 VOC inflection trigger
  with a 60-second PIR latch for a realistic demo flow, fixed WiFi retries and
  MIN_MODEM power mode, fixed Firebase command parsing (getJSON) and an API
  key typo, added pushSensorData() and pollFirebaseSettings() so the app Air
  Quality card and Auto-Spray toggle are now live-connected, and corrected the
  feature_buffer warmup filter. All five trigger paths verified in hardware.
  The full pipeline was demoed live at the MSTI Alumni Reunion Open House
  without issues. Yutong polished the app UI with trigger icons, repositioned
  IAQ badge, reservoir reset, and dual Firebase/ESP32 status header. The
  enclosure upper lid was cast in clear resin from a silicone mold — PLA layer
  texture produced a frosted finish. Lower base CAD updated (height, USB-C,
  PCB mount, mic) and sliced; SLA printer broke and has since been repaired.
credits:
  - name: Lucia
    initials: L
    tags:
      - AuraSync v4 Firmware
      - Enclosure v3 CAD
      - Transparent Lid Casting
      - Open House Demo
  - name: Yutong
    initials: Y
    tags:
      - App UI Polish
      - Transparent Lid Casting
      - Open House Demo
      - Devlog
prior_week_progress:
  pcb-finalize: "partial"
  enclosure-lid: true
  enclosure-base: "partial"
  system-integration: true
planned_next:
  - id: sand-cover
    label: Sand & Finish Transparent Lid
    description: "Sand the cast resin lid to achieve a uniform frosted-glass surface finish, then test fit onto the lower base."
  - id: print-base
    label: Print Enclosure Lower Shell
    description: "SLA printer is repaired — print the lower base in resin, verify dimensional fit against the cast lid and PCB."
  - id: full-assembly
    label: Full Enclosure Assembly
    description: "Assemble upper lid + lower base with all components seated — PCB, LiPo, BME680, PIR, INMP441, atomizer. Run the full state machine to confirm nothing regressed post-assembly."
  - id: pcb-soldering
    label: PCB Final Soldering
    description: "Complete final soldering when the custom PCB arrives — all breakout connectors, atomizer MOSFET, MT3608, and WS2812B ring leads."
  - id: backup-video
    label: Record Backup Demo Video
    description: "Record a complete run-through of all five trigger paths as a fallback in case the live demo has connectivity or environmental issues."
---

## Executive Summary

Four tracks this week.

- **AuraSync v4 firmware** — Lucia overhauled the firmware: added `DEMO_MODE` (3 s sampling, 30 s warmup, relaxed thresholds), rewrote the P3 VOC inflection trigger with a 60-second PIR latch so "spray → walk to sensor" works as a demo flow, fixed WiFi retries and `WIFI_PS_MIN_MODEM`, fixed Firebase `getJSON` parsing and an API key typo, added `pushSensorData()` and `pollFirebaseSettings()` so the app's Air Quality card and Auto-Spray toggle are now live-connected, and corrected the `feature_buffer.h` warmup filter to skip high readings rather than cap them.
- **Open House demo** — The full system was demonstrated live at the MSTI Alumni Reunion Open House. All triggers fired correctly throughout the event and the team received positive feedback from alumni attendees.
- **App UI polish** — Yutong added trigger icons for `iaq_poor` (🌫️) and `p3_shower_end` (🚿), moved the IAQ badge below the gas resistance value, added a reservoir reset flow, and introduced a dual status indicator showing Firebase and ESP32 connection states independently.
- **Enclosure** — The lower base CAD was updated for v3. The transparent upper lid was cast in clear resin using a silicone mold — the PLA layer texture produced a frosted surface. The lower base is modelled and sliced; the SLA printer broke before printing but has been repaired.

## 1. Firmware Refinement — AuraSync v4

### DEMO_MODE

A `DEMO_MODE` compile flag was added (default: enabled) to make the device practical for short classroom demos without waiting 30 minutes for the BSEC2 warm-up.

| Parameter | Normal | DEMO_MODE |
|---|---|---|
| Sampling interval | ~9 s | ~3 s |
| IAQ warm-up | ~30 min | 30 s |
| Detection thresholds | Production-tuned | Relaxed for fast response |

### P3 Inflection + PIR Trigger — Rewrite

The original P3 logic required the VOC inflection point and an active PIR signal to occur simultaneously within a 5-second window. In practice this almost never fires during a demo because a person sprays perfume and then has to walk back to the PIR field of view.

The trigger was rewritten with a **latch mechanism**: when a VOC inflection is detected, a timestamp is recorded. If PIR fires within the next **60 seconds**, the spray is triggered. This supports the natural demo flow of "spray fragrance → walk to device" without needing to be in front of the sensor at the moment of detection.

### WiFi & Firebase Fixes

| Issue | Fix |
|---|---|
| Unreliable WiFi connection | Added 3 retries; each attempt prints progress and failure status code |
| Firebase SSL timeout (`ERROR:mRunUntil1`) | `WIFI_PS_MAX_MODEM` → `WIFI_PS_MIN_MODEM`; modem sleep too aggressive for SSL handshake |
| Command read returning empty string | `getString` → `getJSON` + `FirebaseJsonData`; App sends JSON objects, not plain strings |
| Auth failure | API key character fix: digit `1` → letter `l` in position 4 |

### App Data Sync — New Additions

Two polling functions were added to push device state to Firebase so the app reflects live sensor data:

**`pushSensorData()`** — runs every 5 s. Writes `gas_ohm`, `temp_c`, `humidity_pct`, and `context` to `/sensors/latest`. This is what powers the Air Quality card in the app; previously the card showed no data.

**`pollFirebaseSettings()`** — runs every 10 s. Reads `/settings/autoSprayEnabled`. All three automatic trigger paths (IAQ Poor, Shower CNN, P3 inflection) now gate on this flag — the Auto-Spray toggle in the app now has actual effect.

### feature_buffer.h — Warmup Filter

The warmup filter strategy was corrected:

| Before | After |
|---|---|
| Readings with `gas_ohm > 100k` were capped to 100k before entering the buffer | Readings with `gas_ohm > 60k` are skipped entirely |

Capping created artificially high values that polluted the rolling-max baseline used for normalisation. Skipping them outright prevents this while still allowing the buffer to fill with valid post-warmup readings.

### Verified Trigger Paths

All five trigger paths were confirmed to fire correctly in hardware testing:

1. **Voice** — ESP-SR keyword "spray" detected and routed through the priority queue
2. **App** — Firebase command received and executed from any device state, including SLEEP
3. **IAQ Poor** — On-device MLP classifies air quality as Poor; triggers spray (gated by `autoSprayEnabled`)
4. **Shower CNN** — 1D-CNN probability exceeds threshold; transitions to SPRAYING (gated by `autoSprayEnabled`)
5. **VOC inflection + PIR (P3)** — Latch mechanism: inflection detected → PIR fires within 60 s → spray (gated by `autoSprayEnabled`)

## 2. Full System Integration & Open House Demo

With AuraSync v4 complete, the full pipeline — PIR, ML triggers, Firebase, and app — was run and validated together for the first time.

The team presented AuraSync at the **MSTI Alumni Reunion Open House**. The live system ran throughout the event: attendees could trigger sprays via the app and observe the diffuser respond in real time. All five trigger types were demonstrated. Debugging was smooth with no issues during the event.

## 3. App UI Polish

Four targeted improvements to the mobile app this week.

### Trigger Icon Mapping

Two trigger types were appearing as `❓` with raw key names because they were not yet registered in the app. Both are now properly mapped:

| Firebase key | Label | Icon | Color |
|---|---|---|---|
| `iaq_poor` | IAQ Poor | 🌫️ | Red |
| `p3_shower_end` | Shower | 🚿 | Blue |

### IAQ Pill Position & Overflow Fix

The air quality badge was previously rendered **above** the gas resistance reading. It now appears **below** the kΩ value — matching the visual hierarchy of the other sensor tiles. `numberOfLines={1}` and tighter padding prevent "Moderate" from wrapping on narrow screens.

### Reservoir Reset

A `⟳` button next to the reservoir estimate opens an action sheet:

- **Fill to Full** — resets consumption tracking to 30 ml in one tap
- **Set Amount…** — custom ml entry via native text prompt (iOS); Android falls back to Fill to Full

Reset state is written to Firebase `settings/` and persists across app restarts.

### Device Online Indicator

The header now shows two separate status rows:

| Row | Monitors |
|---|---|
| **App** 🟢 / 🔴 | App ↔ Firebase real-time connection |
| **Device** 🟢 / 🔴 | ESP32 online — inferred from `sensor.updatedAt`; offline if no update in > 2 min |

A 30-second interval re-evaluates device status even when sensor data stops arriving.

## 4. Enclosure

### Lower Base CAD — v3 Updates

Lucia revised the lower base model ahead of SLA printing:

| Change | Detail |
|---|---|
| Upper shell height | Raised to accommodate the atomizer module height |
| USB-C cutout | Added to lower shell for charging access |
| PCB mounting | Revised mounting method for secure fit |
| Microphone placement | Revised position for better acoustic clearance |

Modelling and slicing for the SLA resin printer were completed this week. The printer broke before the run could start — Zubin repaired it over the weekend and printing is scheduled for next week.

### Transparent Upper Lid — Silicone Mold Casting

The upper lid is the transparent section of the enclosure. The goal is a frosted-glass surface finish that diffuses internal LED light softly. Silicone mold casting with clear resin was chosen for the material finish.

#### Mold Design

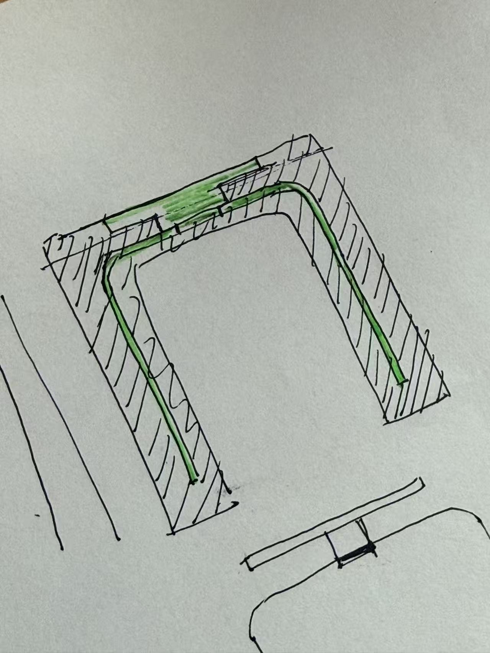
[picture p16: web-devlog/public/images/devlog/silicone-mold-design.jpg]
Silicone mold sketch — single-body mold design using outer shell with internal displacer to minimise silicone volume Mold design — Kevin's single-body approach: outer box + internal displacer saves silicone


Kevin shared a **single-body mold** concept: rather than a two-part split mold, pour silicone around the master inside an outer box, with an internal structure displacing the bulk to reduce material use significantly.

#### Making the Mold

An outer cardboard box was built around the 3D-printed PLA master. Silicone was mixed, degassed under vacuum, then poured.

A **glass bottle** was pressed into the wet silicone as the internal displacer — saving a large volume of material. This worked, but glass was the wrong choice: the silicone cured against the smooth bottle surface and bonded tightly. The bottle was eventually freed by **injecting air with a compressor** to break the seal.

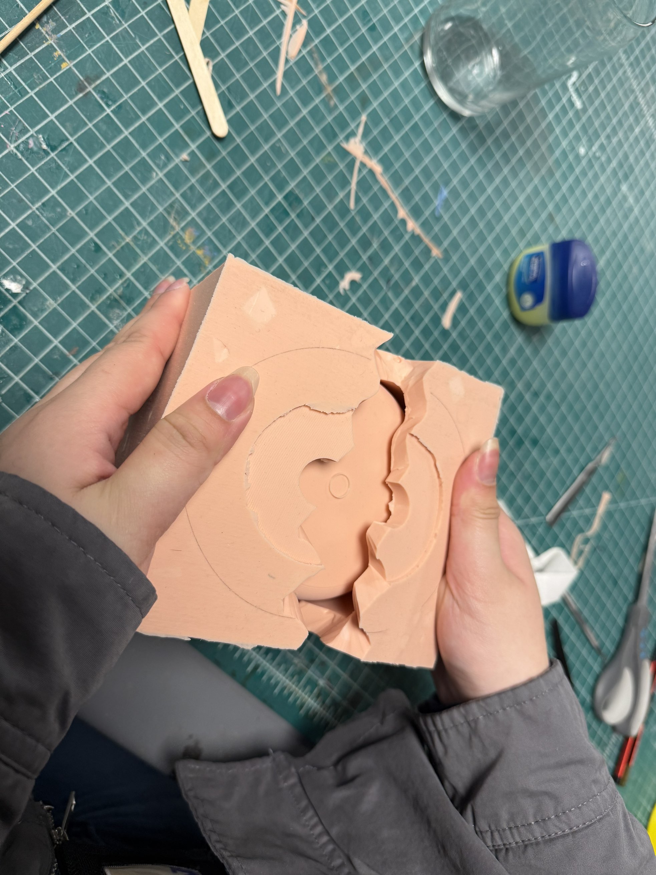
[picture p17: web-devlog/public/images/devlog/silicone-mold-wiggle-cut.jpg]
Cutting the silicone mold to release the cured resin lid — mold cut away in sections where no air gap formed Demoulding the resin lid — silicone cut away in sections to release the cast


#### Casting the Lid

Clear resin (A+B, 1:1 by volume) was mixed, degassed, and poured into the mold. A wooden board was bound across the top to apply even pressure during cure. The resin cured for 48 hours.

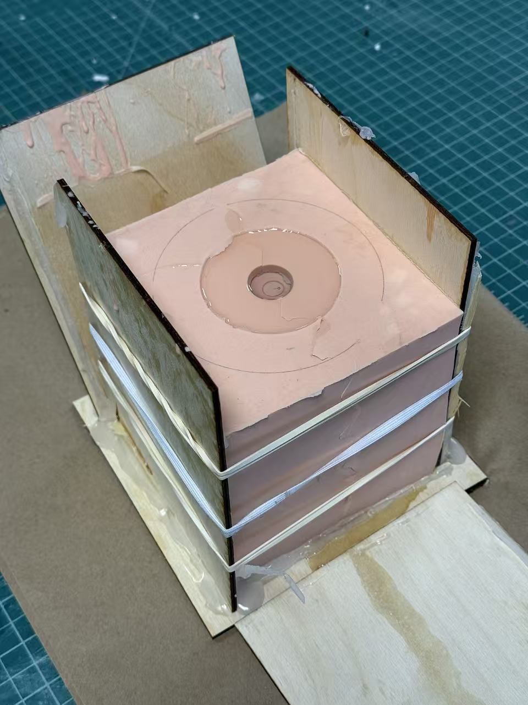
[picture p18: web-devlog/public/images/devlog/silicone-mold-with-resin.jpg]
Resin poured into silicone mold with wooden board bound on top to apply pressure during cure Resin cast in progress — wood board bound down to maintain even pressure


Demolding the cured lid was difficult: the silicone was cast too thick with no air gap, so the lid could not be pulled free. The mold was cut away in sections to release the piece.

#### Result

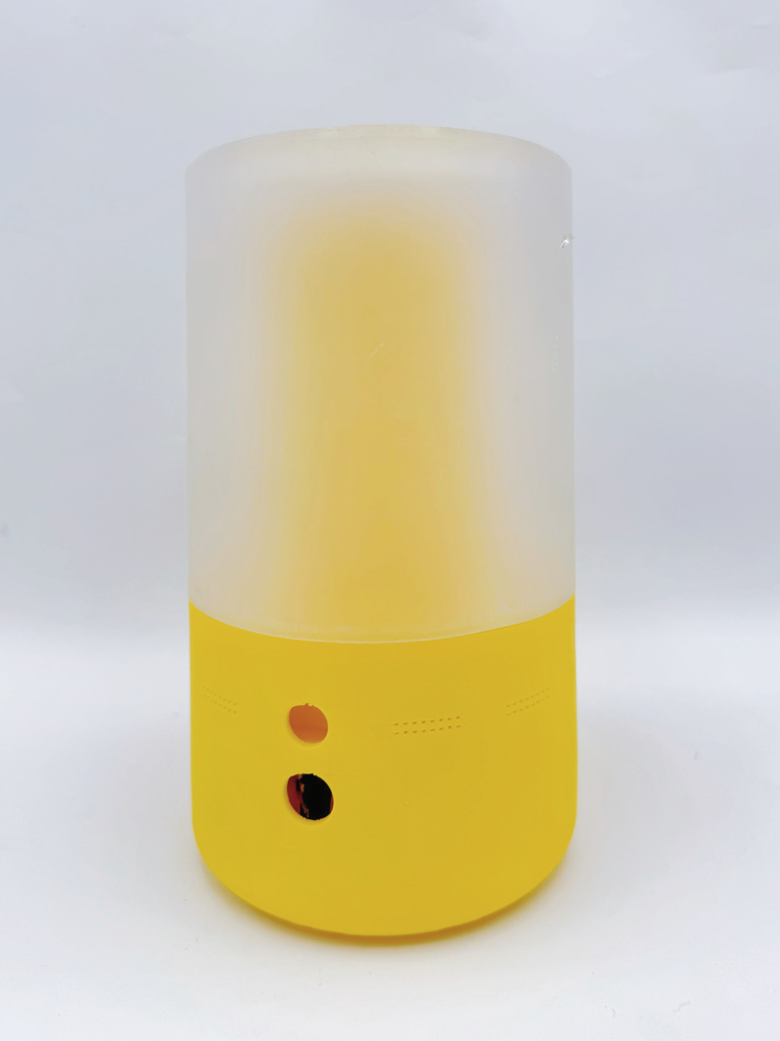
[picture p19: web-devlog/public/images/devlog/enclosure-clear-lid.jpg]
Finished clear resin upper lid — frosted translucent surface from PLA print layer lines Finished upper lid — clear resin with frosted texture from the PLA master's layer lines. Surface sanding only needed.


The PLA print layer lines transferred through the silicone and into the resin surface, producing the intended frosted-glass aesthetic without any coating. Surface sanding is still needed to even out the finish before final assembly.

## Next Steps

| Done | Task | Description |
|:-:|---|---|
| <input type="checkbox" checked /> | **Sand & Finish Transparent Lid** | Sand cast resin lid to a uniform frosted finish; test fit onto lower base. |
| <input type="checkbox" checked /> | **Print Enclosure Lower Shell** | SLA printer repaired — print lower base in resin; verify fit against lid and PCB. |
| <input type="checkbox" checked /> | **Full Enclosure Assembly** | Seat PCB, LiPo, BME680, PIR, INMP441, and atomizer into lower base; close both halves; confirm full state machine runs post-assembly. |
| <input type="checkbox" checked /> | **PCB Final Soldering** | Solder all components when custom PCB arrives — breakout connectors, atomizer MOSFET, MT3608, WS2812B ring leads. |
| <input type="checkbox" /> | **Record Backup Demo Video** | Record a complete run-through of all five trigger paths as a fallback for the live demo. |

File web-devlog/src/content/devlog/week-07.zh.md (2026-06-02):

---
week: 7
date: "2026年5月12日 - 5月18日"
title: "AuraSync v4、Open House 展示、App UI 优化与外壳上盖翻模"
status: "Completed"
show_next_steps: true
summary: >
  本周四条主线。Lucia 将固件升级至 AuraSync v4：新增 DEMO_MODE（3 秒采样、
  30 秒预热），用 60 秒 PIR 锁存机制重写了 P3 VOC 拐点触发，使「喷香水→走到
  传感器前」的演示流程成为可能；修复了 WiFi 重试与 MIN_MODEM 省电模式、Firebase
  命令解析（改用 getJSON）及 API Key 字符错误；新增 pushSensorData() 和
  pollFirebaseSettings()，应用的「空气质量」卡和 Auto-Spray 开关现已实时联动；
  修正了 feature_buffer 预热过滤策略。五条触发路径均已在硬件上验证。整机在
  MSTI 校友 Open House 现场展示，运行顺畅。Yutong 优化了 App UI：触发图标补全、
  IAQ 气泡位置修复、储液槽重置、Firebase/ESP32 双状态顶栏。外壳上盖以硅胶模具
  翻模透明树脂完成，层纹形成磨砂质感；下底座 CAD 完成更新并切片，打印机故障
  已修复。
credits:
  - name: Lucia
    initials: L
    tags:
      - AuraSync v4 固件
      - 外壳 v3 CAD
      - 透明上盖翻模
      - Open House 展示
  - name: Yutong
    initials: Y
    tags:
      - App UI 优化
      - 透明上盖翻模
      - Open House 展示
      - 开发日志
prior_week_progress:
  pcb-finalize: "partial"
  enclosure-lid: true
  enclosure-base: "partial"
  system-integration: true
planned_next:
  - id: sand-cover
    label: 打磨并修整透明上盖
    description: "对翻模完成的透明树脂上盖进行打磨，获得均匀的磨砂玻璃质感，随后与下底座进行配合测试。"
  - id: print-base
    label: 打印外壳下底座
    description: "SLA 打印机已修复——用树脂打印下底座，验证与上盖及 PCB 的尺寸配合。"
  - id: full-assembly
    label: 整机组装
    description: "将上盖与下底座合拢，装入全部组件——PCB、LiPo、BME680、PIR、INMP441、雾化片。运行完整状态机确认组装后功能正常。"
  - id: pcb-soldering
    label: PCB 最终焊接
    description: "定制 PCB 到货后完成全部焊接——接插件、雾化片 MOSFET、MT3608 及 WS2812B 灯带引线。"
  - id: backup-video
    label: 录制备用演示视频
    description: "录制一段涵盖五条触发路径的完整演示视频，以备现场演示出现网络或环境问题时使用。"
---

## 执行摘要

本周四条主线。

- **AuraSync v4 固件** — Lucia 对固件进行了全面整合：新增 `DEMO_MODE`（3 秒采样、30 秒预热、宽松阈值），用 60 秒 PIR 锁存机制重写 P3 VOC 拐点触发，修复 WiFi 重试与 `WIFI_PS_MIN_MODEM`，修复 Firebase `getJSON` 解析和 API Key 字符错误，新增 `pushSensorData()` 和 `pollFirebaseSettings()` 使应用「空气质量」卡和 Auto-Spray 开关实时生效，并修正 `feature_buffer.h` 预热过滤策略；全部五条触发路径已在硬件上验证完成。
- **Open House 现场展示** — 整机系统在 MSTI 校友回归 Open House 活动中进行了实际演示，五种触发类型均正常触发，运行顺畅，获得参与者的积极反馈。
- **App UI 优化** — Yutong 为 `iaq_poor`（🌫️）和 `p3_shower_end`（🚿）补全了触发图标，将 IAQ 气泡移至阻值下方，新增储液槽重置功能，并在顶栏增加了独立显示 Firebase 和 ESP32 连接状态的双行指示器。
- **外壳** — 下底座 CAD 完成 v3 更新。透明上盖以硅胶模具翻模透明树脂制作完成，PLA 层纹带来自然磨砂质感。下底座已建模切片，但打印机故障，修复后将于下周打印。

## 1. 固件整合——AuraSync v4

### DEMO_MODE

新增 `DEMO_MODE` 编译标志（默认开启），使设备无需等待 30 分钟预热即可在课堂演示中使用。

| 参数 | 正常模式 | DEMO_MODE |
|---|---|---|
| 采样间隔 | ~9 秒 | ~3 秒 |
| IAQ 预热时间 | ~30 分钟 | 30 秒 |
| 检测阈值 | 生产调优 | 宽松，响应更快 |

### P3 拐点 + PIR 触发——重写

原有 P3 逻辑要求 VOC 拐点与 PIR 激活同时发生（5 秒窗口内），实际演示中几乎无法触发——因为喷香水之后还需走回 PIR 感应区域。

本次以**锁存机制**重写：检测到 VOC 拐点时记录时间戳；若 PIR 在随后 **60 秒内**触发，则执行喷雾。支持「喷香水 → 走到设备前」的自然演示流程。

### WiFi 与 Firebase 修复

| 问题 | 修复方案 |
|---|---|
| WiFi 连接不稳定 | 新增 3 次重试；每次打印进度和失败状态码 |
| Firebase SSL 超时（`ERROR:mRunUntil1`） | `WIFI_PS_MAX_MODEM` → `WIFI_PS_MIN_MODEM`；原省电模式对 SSL 握手过于激进 |
| 命令读取返回空字符串 | `getString` → `getJSON` + `FirebaseJsonData`；应用发送的是 JSON 对象，非纯字符串 |
| 鉴权失败 | API Key 第 4 位字符修正：数字 `1` → 字母 `l` |

### 应用数据同步——新增

新增两个轮询函数，将设备状态实时推送至 Firebase，应用由此获得真实数据：

**`pushSensorData()`** — 每 5 秒执行。将 `gas_ohm`、`temp_c`、`humidity_pct`、`context` 写入 `/sensors/latest`。应用的「空气质量」卡此前无数据，现在已实时联动。

**`pollFirebaseSettings()`** — 每 10 秒执行。读取 `/settings/autoSprayEnabled`。IAQ Poor、淋浴 CNN、P3 拐点三条自动触发路径现在均检查此标志——应用的 Auto-Spray 开关现在真正生效。

### feature_buffer.h——预热过滤修正

| 修改前 | 修改后 |
|---|---|
| `gas_ohm > 100k` 的读数被截断为 100k 存入 buffer | `gas_ohm > 60k` 的读数直接跳过，不进入 buffer |

截断会在 buffer 中引入人造高值，污染归一化所用的 rolling max 基线。改为直接跳过，使 buffer 只包含预热后的有效读数。

### 五条触发路径验证

全部五条触发路径均在硬件上完成验证：

1. **语音** — ESP-SR 识别关键词 "spray" 并通过优先级队列路由
2. **应用** — Firebase 指令可从任意状态（含 SLEEP）接收并执行
3. **IAQ Poor** — 端侧 MLP 将空气质量分类为 Poor，触发喷雾（受 `autoSprayEnabled` 控制）
4. **淋浴 CNN** — 1D-CNN 概率超过阈值，切换至 SPRAYING（受 `autoSprayEnabled` 控制）
5. **VOC 拐点 + PIR（P3）** — 锁存机制：检测到拐点 → PIR 在 60 秒内触发 → 喷雾（受 `autoSprayEnabled` 控制）

## 2. 整机集成与 Open House 展示

AuraSync v4 完成后，PIR、ML 触发、Firebase 和应用完整流程首次在所有子系统同时运行状态下完成端到端验证。

团队在 **MSTI 校友回归 Open House** 活动中展示了 AuraSync 实物系统。现场系统全程运行，参与者可通过应用触发喷雾并实时观察设备响应，五种触发类型均有演示。展示期间调试顺利，未出现任何问题。

## 3. App UI 优化

本周对移动端应用进行了四项针对性改进。

### 触发类型图标补全

此前有两种触发类型在活动记录中显示为 `❓` 和原始键名，现已正式注册：

| Firebase 键 | 标签 | 图标 | 颜色 |
|---|---|---|---|
| `iaq_poor` | IAQ Poor | 🌫️ | 红色 |
| `p3_shower_end` | Shower | 🚿 | 蓝色 |

### IAQ 气泡位置与换行修复

气体质量标签（Good / Moderate / Poor）原先显示在 kΩ 数值**上方**，现已调整至**下方**，与温度和湿度卡片的视觉层次保持一致。同时添加 `numberOfLines={1}` 限制和更小的水平内边距，防止"Moderate"在窄屏上换行。

### 储液槽重置

储液槽估算条右侧新增 `⟳` 按钮，点击后弹出操作菜单：

- **Fill to Full** — 一键将消耗记录重置为 30 ml
- **Set Amount…** — iOS 原生文字输入自定义容量；Android 暂退化为一键归满

重置状态写入 Firebase `settings/`，重启应用后数据持久保留。

### 设备在线状态指示

顶栏改为两行独立状态：

| 行 | 监控对象 |
|---|---|
| **App** 🟢 / 🔴 | 应用 ↔ Firebase 实时连接 |
| **Device** 🟢 / 🔴 | ESP32 是否在线——根据 `sensor.updatedAt` 推断；超过 2 分钟未更新则判定离线 |

30 秒定时器周期性重新评估，即使传感器数据停止更新，指示灯也能及时变红。

## 4. 外壳

### 下底座 CAD 更新——v3

Lucia 在 SLA 打印前对下底座模型进行了修订：

| 改动 | 说明 |
|---|---|
| 上壳高度 | 上调以容纳雾化模块高度 |
| USB-C 开口 | 在下壳增加充电开口 |
| PCB 固定方式 | 修订固定方案，确保安装稳固 |
| 麦克风位置 | 调整位置以改善声学间隙 |

本周完成建模与切片，打印机在运行前发生故障。Zubin 于周末完成维修，打印安排在下周进行。

### 透明上盖——硅胶翻模

上盖是外壳的透明段，目标是磨砂玻璃质感，使内部 LED 灯光柔和透出。选择硅胶模具 + 透明树脂工艺实现这一效果。

#### 设计方案

硅胶模具草图——单体模具设计，以内部占位结构大幅节省硅胶用量 模具设计草图——Kevin 分享的单体模思路：外箱 + 内部占位结构节省硅胶

Kevin 分享了**单体模**思路：不采用传统两开模，而是在外箱内将硅胶直接浇注于母模周围，同时以内部占位结构排开大体积硅胶，显著降低材料用量。

#### 制作硅胶模具

以硬纸板在 3D 打印 PLA 母模外搭建外箱。硅胶按比例调配后，在真空腔中脱泡再灌注，防止气泡残留。

灌注过程中将一只**玻璃瓶**压入湿硅胶中央作为内部占位结构，节省了大量硅胶。但使用玻璃是个错误的决定——硅胶固化后紧贴光滑玻璃壁形成强附着，瓶子几乎无法取出。最终通过**气泵注气**打破密封，成功将玻璃瓶取出。

脱模——硅胶与树脂上盖之间无气隙，分段切割硅胶模具以释放成品 树脂脱模——硅胶过厚且无气隙，分段切割模具取出上盖

#### 灌注树脂

透明树脂（A+B 1:1 体积比）调配后脱泡，灌入硅胶模具，用木板绑在顶部施加均匀压力，固化 48 小时。

树脂灌入硅胶模具，顶部以木板绑紧施压，固化中 树脂灌注中——木板绑紧维持均匀压力

固化后脱模困难——硅胶壁过厚且树脂与模具之间无气隙，成品无法直接拔出，最终分段切割硅胶模具才将上盖取出。

#### 成果

成品透明树脂上盖——来自 PLA 母模打印层纹的天然磨砂质感，尚需打磨 成品上盖——透明树脂，PLA 层纹赋予的天然磨砂质感；表面打磨后即可使用

PLA 打印层纹经由硅胶转印至树脂表面，形成预期的磨砂玻璃效果，无需额外涂层。后续需对表面进行打磨，获得更均匀的质感后即可装配。

## 下一步计划

| 完成 | 任务 | 说明 |
|:-:|---|---|
| <input type="checkbox" checked /> | **打磨并修整透明上盖** | 对树脂上盖表面进行打磨，获得均匀磨砂质感，随后与下底座进行配合测试。 |
| <input type="checkbox" checked /> | **打印外壳下底座** | SLA 打印机已修复——打印下底座，验证与上盖及 PCB 的尺寸配合。 |
| <input type="checkbox" checked /> | **整机组装** | 将上盖与下底座合拢，装入全部组件；运行完整状态机确认功能正常。 |
| <input type="checkbox" checked /> | **PCB 最终焊接** | 定制 PCB 到货后完成全部焊接——接插件、MOSFET、MT3608 及 WS2812B 灯带引线。 |
| <input type="checkbox" /> | **录制备用演示视频** | 录制五条触发路径完整演示视频，以备现场连接问题时使用。 |

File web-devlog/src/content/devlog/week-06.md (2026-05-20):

---
week: 6
date: "May 5 - May 11, 2026"
title: "ML On-Device Inference, Enclosure v2, PCB v1 & Firebase Validation"
status: "Completed"
show_next_steps: true
summary: >
  Four tracks converged this week. Lucia exported the trained IAQ MLP and
  Shower CNN weights as C float arrays and wired them into the AuraSync
  firmware — the device now classifies air quality and detects shower events
  entirely on-chip with no cloud inference step. The Firebase reverse-control
  loop was debugged and validated end-to-end with approximately 1-second
  round-trip latency. The enclosure was redesigned from a rectangular box to
  a cylindrical two-part snap-fit form factor and printed in PLA. Yutong
  designed the PCB as a circular board (R = 45 mm) fabricated on the GIX
  LPKF milling machine, and completed the Milestone 2 slide deck.
credits:
  - name: Lucia
    initials: L
    tags:
      - ML Firmware Integration
      - Enclosure v2
      - Milestone 2 Slides
  - name: Yutong
    initials: Y
    tags:
      - PCB Design
      - Milestone 2 Slides
      - Devlog
prior_week_progress:
  shower-data-and-retrain: true
  extreme-case-testing: "partial"
  enclosure: true
  pcb: true
planned_next:
  - id: pcb-finalize
    label: Finalize PCB & Soldering
    description: "Complete PCB v1 bring-up — power from LiPo + MT3608, verify all GPIO connections, confirm no shorts. Cut and solder PCB v2 to fix any routing or clearance issues found during testing."
  - id: enclosure-lid
    label: Enclosure Upper Lid
    description: "Cast the upper lid using a silicone mold and clear resin (A+B). The 3D-printed master's layer texture provides a natural frosted finish without post-processing."
  - id: enclosure-base
    label: Enclosure Lower Base
    description: "Model and slice the lower base for SLA resin printing. The base houses the PCB, battery, sensors, and atomizer, and must align with the snap-fit interface of the cast upper lid."
  - id: system-integration
    label: Full System Integration Test
    description: "Run all sensors + ML triggers + Firebase + app together as a complete pipeline — validate PIR wake → ML event detection → spray actuation → cooldown → Firebase state reflected in app under real conditions."
---

## Executive Summary

Four parallel tracks this week.

- **ML on-device inference** — Lucia exported trained model weights as C float arrays and integrated them into the AuraSync firmware. The device now runs IAQ classification and shower detection entirely on-chip with no cloud step.
- **Firebase validation** — The reverse-control loop (app → ESP32 → actuate → ack) was debugged and validated end-to-end with approximately 1-second round-trip latency.
- **Enclosure v2** — Redesigned from a rectangular box to a cylindrical two-part snap-fit. Printed in PLA; both sections confirmed to fit and separate cleanly.
- **PCB v1** — Yutong designed a circular PCB (R = 45 mm) using JST connector headers to mount all breakout boards. Fabricated at GIX on the LPKF milling machine and partially soldered.

## 1. ML On-Device Inference

### Model Export

Lucia converted the trained Python models to C float arrays using a custom export script. Three header files were added to the AuraSync sketch folder:

| File | Contents |
|---|---|
| `iaq_model.h` | IAQ MLP: StandardScaler parameters + weight matrices for two hidden layers (64 → 32) and a 3-class softmax output (Good / Moderate / Poor) |
| `shower_model.h` | Shower 1D-CNN: all conv, pool, and dense weight arrays |
| `feature_buffer.h` | 120-entry ring buffer (20-minute window) + `fb_push()`, `computeIAQFeatures()`, `computeShowerWindow()` |

The ring buffer stores one BSEC2 LP sample every 9–10 seconds. Feature engineering runs entirely inside the header functions, matching the training pipeline exactly — same 5-minute delta calculations, same 10-minute rolling statistics, same StandardScaler parameters.

### Firmware Integration

The AuraSync state machine now calls ML inference on each BSEC2 LP callback:

1. `fb_push()` adds the new reading (temperature, humidity, IAQ index) to the ring buffer.
2. When the buffer has at least 60 samples, `computeIAQFeatures()` builds the 10-feature vector and the IAQ MLP classifies air quality (Good / Moderate / Poor).
3. When the buffer has at least 30 samples, `computeShowerWindow()` builds the 30×6 normalised window and the Shower CNN outputs a probability.
4. If shower probability exceeds 0.65, the state machine transitions to SPRAYING.

An IAQ accuracy gate prevents classification during BSEC2 warm-up: readings with `iaq_accuracy < 1` are skipped for the first ~30 minutes after cold start.

### Round 2 Results (BSEC2 Data)

The switch from raw `gas_ohm` + rolling normalisation to the BSEC2 calibrated IAQ index collapsed inter-session IAQ variance from **±0.165** to **±0.012** — roughly a 14× improvement in feature stability.

| Model | Metric | Round 1 | Round 2 |
|---|---|---|---|
| IAQ MLP | CV Macro F1 variance | ±0.165 | ±0.012 |
| Shower CNN | Val F1 | 0.77 | **0.902** |
| Shower CNN | ROC-AUC | 0.94 | 0.94 |

The Shower CNN val F1 of 0.902 exceeds the ≥ 0.85 target set in week 5.

## 2. Firebase Reverse Control — Validation

The Firebase command protocol was designed in week 5. This week the ESP32 polling loop was debugged and the full round trip was validated end-to-end.

### Bug Fix

The original implementation used `getString` to read `/commands/action`, which fails silently when the node contains a JSON object. The fix:

| Before | After |
|---|---|
| `getString` → empty string on JSON node | `getJSON` + `FirebaseJsonData` → correct parse |
| Ack: `setString(..., "")` (empty string ≠ null) | Ack: `deleteNode("/commands/action")` |

The app's `onValue` listener checks `snap.val() === null` for confirmation — node deletion is the correct acknowledgement signal.

A WiFi power-save bug was also fixed: `WIFI_PS_MAX_MODEM` caused the radio to sleep too aggressively during SSL handshake, producing `ERROR:mRunUntil1: SSL internals timed out!`. Changed to `WIFI_PS_MIN_MODEM`.

Round-trip latency from app button tap to ESP32 actuation and app confirmation is approximately **1 second** under home WiFi conditions.

## 3. Enclosure v2

### Target Vision

The goal is a compact consumer-product form factor — transparent upper shell exposing the fragrance bottle, white base, and a breathing LED showing interaction state.

### CAD Design

The enclosure is a **cylindrical two-part snap-fit**. The upper cylinder holds the fragrance reservoir and atomizer. The lower base houses the PCB, battery, and all sensors, and is where all the interaction features are resolved.

**Feature decisions on the lower base:**

**Microphone** — A circumferential slot runs around the full perimeter of the base. A single hole was not enough for reliable audio capture; the continuous slot improves pickup from any angle and reduces sensitivity to device orientation.

**PIR sensor** — The AM312 mini PIR faces directly outward through a front-facing opening. Flush exposure gives it an unobstructed field of view without a separate lens or housing.

**LED indicator** — Currently a single indicator opening. Future versions may include an internal LED strip for a breathing-light effect that communicates device state (idle / spraying / cooldown) through the enclosure wall. The transparent upper shell in the final version would make this especially visible.

### Printed Prototype

Both sections fit and separate cleanly. The current print is a structural prototype in yellow PLA — not the final material or colour.

### Next Iterations

| Item | Detail |
|---|---|
| Structural mounting | After PCB v1 bring-up, design mounting points, cable routing paths, and reserved space for the LiPo battery and fragrance container inside the base |
| Component fit verification | Confirm clearances once final PCB dimensions are fixed; add USB-C cutout and secure mounting method |
| High-fidelity finish | 3D print master → resin casting for smooth surface finish; target transparent upper + white base (tentative) |
| LED lighting | Evaluate internal LED strip for breathing-light interaction states visible through the enclosure wall |
| Fragrance bottle | Source a bottle sized to fit the inner cylinder diameter |

## 4. PCB Design v1

### Design

Because all components are purchased as breakout boards, the PCB uses **JST connector headers** as footprints rather than soldering components directly. Components on the board:

- XIAO ESP32-S3
- BME680 breakout
- INMP441 microphone breakout
- PIR sensor connector
- Atomizer MOSFET drive circuit
- MT3608 boost converter (footprint drawn from scratch)
- LiPo connector

The board is **circular with radius 45 mm** to fit the cylindrical enclosure base.

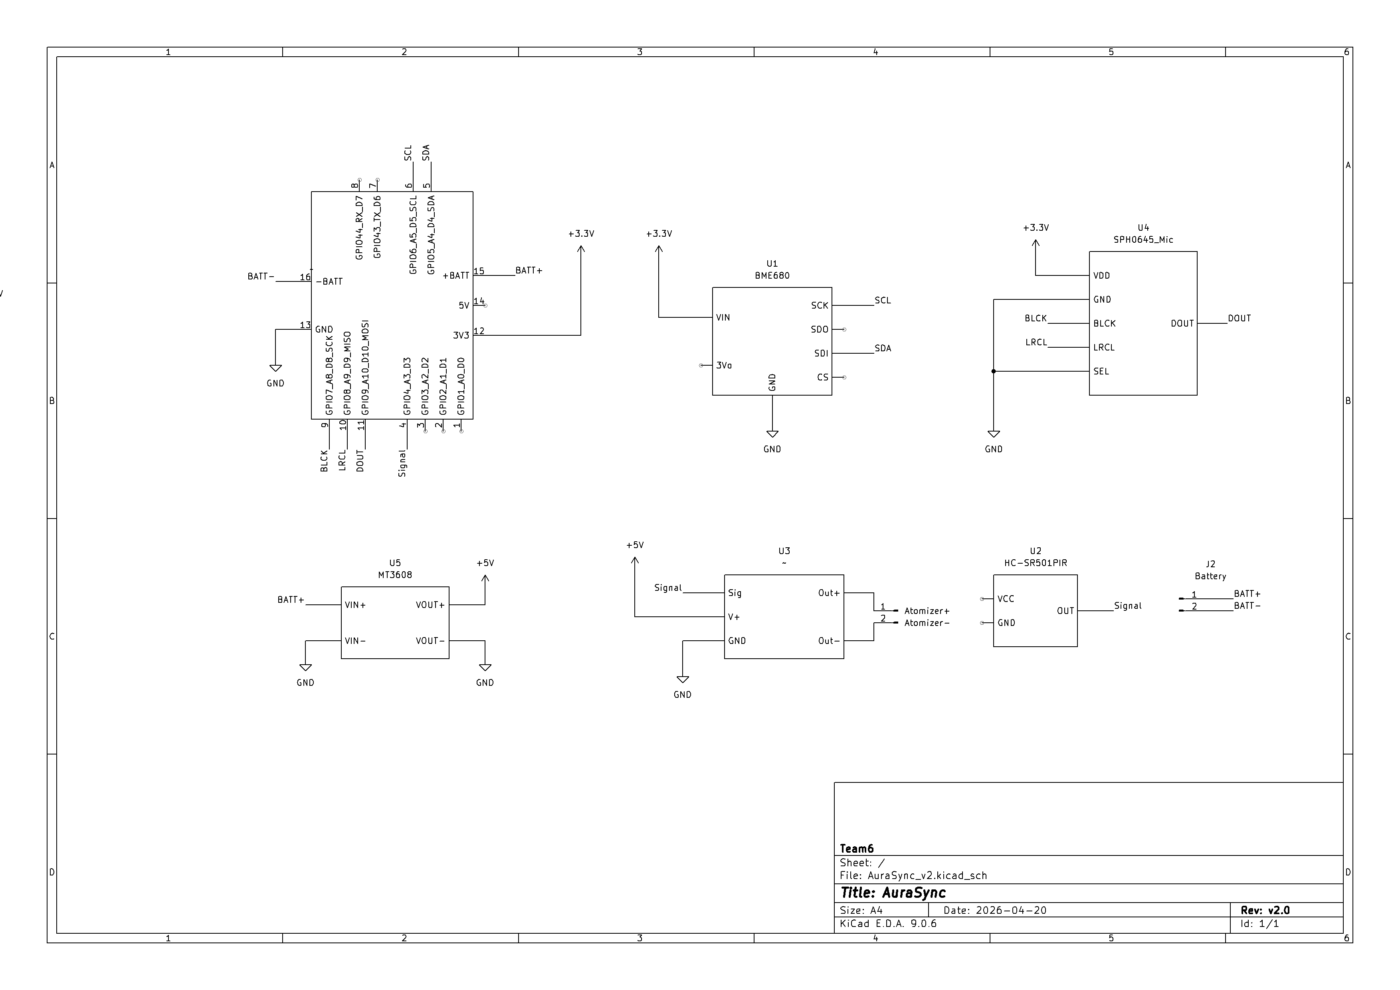
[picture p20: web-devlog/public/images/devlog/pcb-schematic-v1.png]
PCB v1 schematic — all breakout boards connected via JST headers PCB v1 schematic


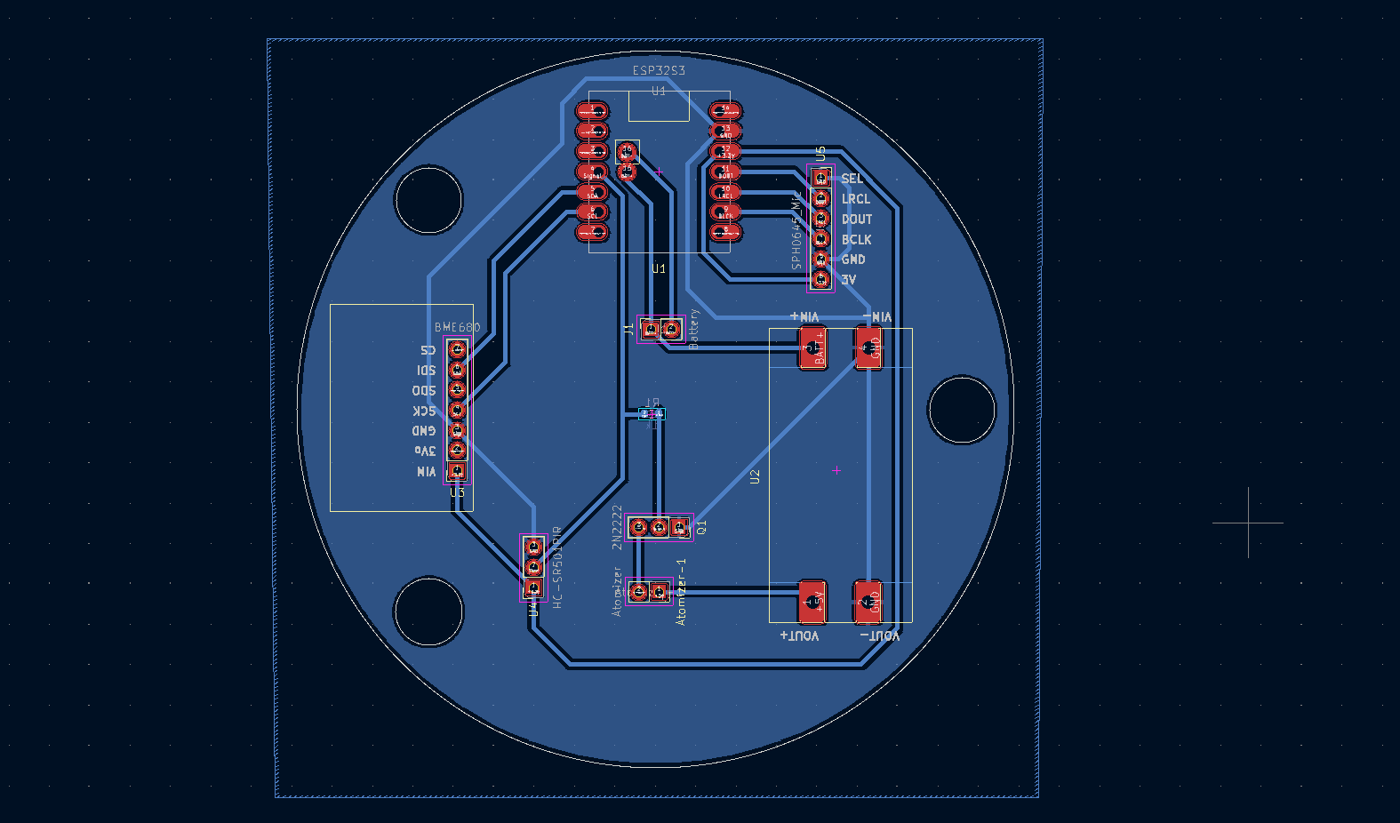
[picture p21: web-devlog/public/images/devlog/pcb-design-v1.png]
PCB v1 layout in KiCAD — circular board R=45mm with JST connector footprints PCB v1 PCB layout


### Fabrication

The board was manufactured at **GIX using the LPKF PCB milling machine**. Milling confirmed that the circular board fits inside the enclosure lower base and gave a first look at trace quality and connector spacing.

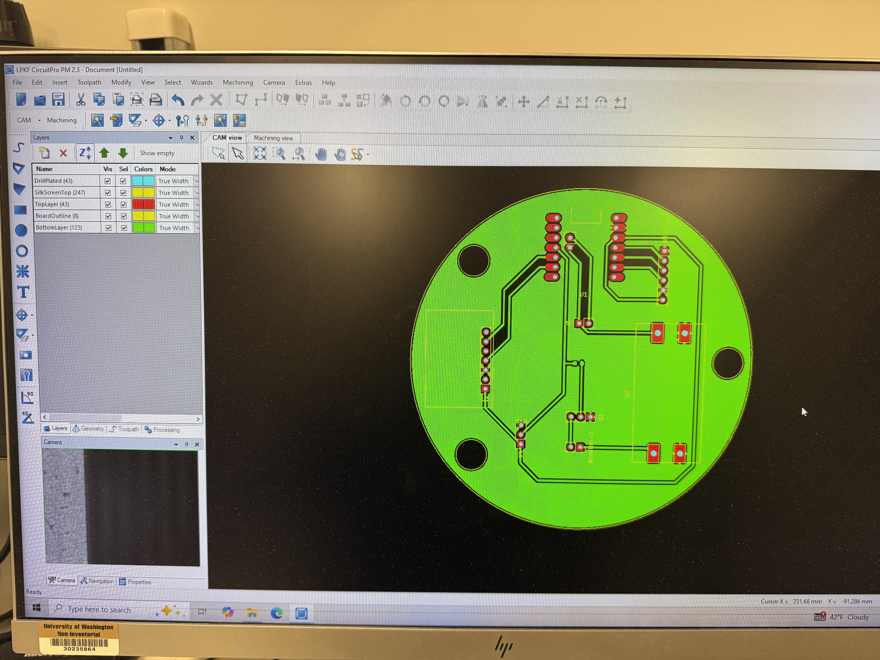
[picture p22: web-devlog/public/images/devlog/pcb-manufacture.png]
PCB v1 after LPKF milling PCB v1 milled on the GIX LPKF machine — board cut and ready for soldering


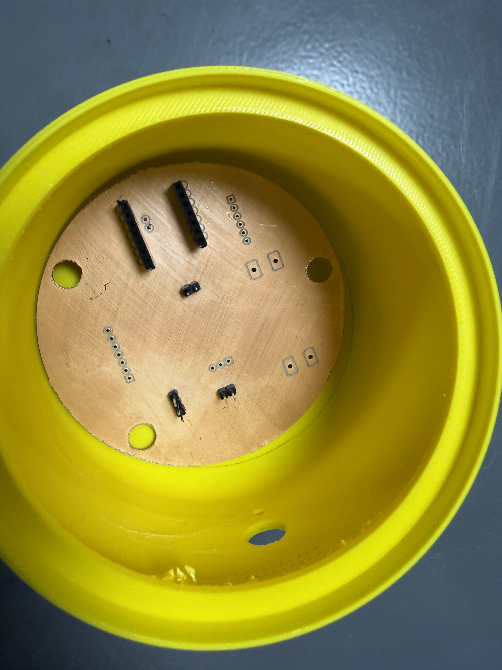
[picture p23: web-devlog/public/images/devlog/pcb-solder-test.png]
PCB v1 partially soldered PCB v1 partially soldered — subsystem bring-up in progress


**Current status:** board is cut and partially soldered. Next step is functional testing of each subsystem on the PCB, then a second revision to fix any spacing or routing issues before full assembly.

## Next Steps

| Done | Task | Description |
|:-:|---|---|
| <input type="checkbox" /> | **Finalize PCB & Soldering** | Complete PCB v1 bring-up; power from LiPo + MT3608; verify GPIO pinout and confirm no shorts. Cut and solder PCB v2 to address any issues. |
| <input type="checkbox" /> | **Enclosure Upper Lid** | Cast the upper lid using a silicone mold and clear resin (A+B). The PLA master's layer texture gives a natural frosted finish. |
| <input type="checkbox" /> | **Enclosure Lower Base** | Model and slice the lower base for SLA resin printing; must align with the snap-fit interface of the cast lid. |
| <input type="checkbox" /> | **Full System Integration Test** | Run all sensors + ML + Firebase + app together as one pipeline under real conditions. |

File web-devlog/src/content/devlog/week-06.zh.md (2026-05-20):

---
week: 6
date: "2026年5月5日 - 5月11日"
title: "ML 端侧推理、外壳 v2、PCB v1 与 Firebase 验证"
status: "Completed"
show_next_steps: true
summary: >
  本周四条并行主线同步推进。Lucia 将训练好的 IAQ MLP 和淋浴 CNN 权重导出为
  C 浮点数组并集成进 AuraSync 固件——设备现可完全在芯片上完成空气质量分类
  和淋浴事件检测，无需云端推理。Firebase 反向控制回路完成端到端调试与验证，
  往返延迟约 1 秒。外壳从矩形盒体重新设计为圆柱形两段卡扣结构并用 PLA 打印。
  Yutong 设计了圆形 PCB（R = 45 mm），在 GIX LPKF 铣床上完成打样，
  并完成了 Milestone 2 幻灯片。
credits:
  - name: Lucia
    initials: L
    tags:
      - ML 固件集成
      - 外壳 v2
      - Milestone 2 幻灯片
  - name: Yutong
    initials: Y
    tags:
      - PCB 设计
      - Milestone 2 幻灯片
      - 开发日志
prior_week_progress:
  shower-data-and-retrain: true
  extreme-case-testing: "partial"
  enclosure: true
  pcb: true
planned_next:
  - id: pcb-finalize
    label: PCB 最终焊接与测试
    description: "完成 PCB v1 通电测试——LiPo + MT3608 供电，验证所有 GPIO 接线，确认无短路。根据发现的布线或间距问题打样并焊接 PCB v2。"
  - id: enclosure-lid
    label: 外壳上盖
    description: "以硅胶模具翻模透明树脂上盖（A+B 双组分）。3D 打印母模的层纹肌理天然形成磨砂质感，无需后处理。"
  - id: enclosure-base
    label: 外壳下底座
    description: "完成下底座建模并切片，使用 SLA 树脂打印机打印。底座需容纳 PCB、电池、传感器和雾化片，并与上盖的卡扣接口精确对齐。"
  - id: system-integration
    label: 整机系统集成测试
    description: "所有传感器 + ML 触发器 + Firebase + 应用同时运行，在真实条件下验证完整流程：PIR 唤醒 → ML 事件检测 → 喷雾执行 → 冷却生效 → 应用状态实时同步。"
---

## 执行摘要

本周四条并行主线。

- **ML 端侧推理** — Lucia 将训练好的模型权重导出为 C 浮点数组并集成进 AuraSync 固件。设备现在完全在芯片上运行 IAQ 分类和淋浴检测，无需云端步骤。
- **Firebase 验证** — 反向控制回路（应用 → ESP32 → 执行 → 确认）完成端到端调试与验证，往返延迟约 1 秒。
- **外壳 v2** — 从矩形盒体重新设计为圆柱形两段卡扣结构，PLA 打印完成，两段拼合与分离均顺畅。
- **PCB v1** — Yutong 设计了使用 JST 接插件封装的圆形 PCB（R = 45 mm），在 GIX LPKF 铣床上完成打样，并已部分焊接。

## 1. ML 端侧推理

### 模型导出

Lucia 使用自定义导出脚本将训练好的 Python 模型转换为 C 浮点数组，并将三个头文件加入 AuraSync 项目目录：

| 文件 | 内容 |
|---|---|
| `iaq_model.h` | IAQ MLP：StandardScaler 参数 + 两个隐藏层（64 → 32）权重矩阵 + 3 类 softmax 输出（Good / Moderate / Poor） |
| `shower_model.h` | 淋浴 1D-CNN：全部卷积、池化和全连接层权重数组 |
| `feature_buffer.h` | 120 项环形缓冲区（20 分钟窗口）+ `fb_push()`、`computeIAQFeatures()`、`computeShowerWindow()` |

环形缓冲区每 9–10 秒存入一条 BSEC2 LP 采样。特征工程完全在头文件函数内完成，与训练流水线完全对应——相同的 5 分钟差分计算、相同的 10 分钟滚动统计、相同的 StandardScaler 参数。

### 固件集成

AuraSync 状态机现在在每次 BSEC2 LP 回调时执行 ML 推理：

1. `fb_push()` 将新读数（温度、湿度、IAQ 指数）存入环形缓冲区。
2. 缓冲区满 60 条后，`computeIAQFeatures()` 构建 10 维特征向量，IAQ MLP 分类空气质量（Good / Moderate / Poor）。
3. 缓冲区满 30 条后，`computeShowerWindow()` 构建 30×6 归一化窗口，淋浴 CNN 输出概率值。
4. 淋浴概率超过 0.65 时，状态机切换至 SPRAYING 状态。

IAQ 精度门控防止 BSEC2 预热期间的误分类：冷启动后约 30 分钟内，`iaq_accuracy < 1` 的读数不参与分类。

### 第二轮结果（BSEC2 数据）

从原始 `gas_ohm` + 滚动归一化切换到 BSEC2 标定 IAQ 指数后，会话间 IAQ 方差从 **±0.165** 压缩至 **±0.012**——特征稳定性提升约 14 倍。

| 模型 | 指标 | 第一轮 | 第二轮 |
|---|---|---|---|
| IAQ MLP | CV Macro F1 方差 | ±0.165 | ±0.012 |
| 淋浴 CNN | Val F1 | 0.77 | **0.902** |
| 淋浴 CNN | ROC-AUC | 0.94 | 0.94 |

淋浴 CNN val F1 = 0.902，超过第 5 周设定的 ≥ 0.85 目标。

## 2. Firebase 反向控制——验证

Firebase 指令协议在第 5 周已完成设计。本周对 ESP32 轮询回路进行了调试，端到端完整回路得到验证。

### Bug 修复

原实现用 `getString` 读取 `/commands/action` 节点，当节点存储的是 JSON 对象时会静默失败。修复方案：

| 修改前 | 修改后 |
|---|---|
| `getString` → JSON 节点返回空字符串 | `getJSON` + `FirebaseJsonData` → 正确解析 |
| 确认：`setString(..., "")` （空字符串 ≠ null） | 确认：`deleteNode("/commands/action")` |

应用侧 `onValue` 监听器通过 `snap.val() === null` 判断指令已被接收——节点删除是正确的确认信号。

同时修复了一个 WiFi 省电模式 Bug：`WIFI_PS_MAX_MODEM` 导致无线电在 SSL 握手期间休眠过于激进，产生 `ERROR:mRunUntil1: SSL internals timed out!`。已改为 `WIFI_PS_MIN_MODEM`。

从应用点击按钮到 ESP32 执行喷雾并收到确认，在家庭 WiFi 环境下往返延迟约 **1 秒**。

## 3. 外壳 v2

### 目标效果

目标是紧凑的消费产品形态——透明上壳展示香氛瓶，白色底座，呼吸灯显示交互状态。

### CAD 设计

外壳为**圆柱形两段卡扣结构**。上筒容纳香氛储液和雾化片，下底座容纳 PCB、电池和全部传感器，所有交互功能均在此集中布局。

**下底座各功能设计：**

**麦克风** — 沿底座整圈开了一道环形槽。单一开孔收音效果不足；环形连续槽可从任意方向拾音，降低对设备朝向的依赖。

**PIR 传感器** — AM312 小型 PIR 正对正面，通过开孔直接露出。齐平露出无需额外透镜或外壳，视场角不受遮挡。

**指示灯** — 目前为单一指示灯开孔。后续版本考虑内置 LED 灯带，以呼吸灯效果呈现设备状态（待机 / 喷雾 / 冷却），透过外壳壁可见。最终透明上壳版本会使灯光效果尤为突出。

### 打印原型

两段拼合与分离均顺畅。当前打印件为黄色 PLA 结构验证原型，并非最终材料与颜色。

### 后续迭代

| 项目 | 说明 |
|---|---|
| 结构固定 | PCB v1 通电测试后，设计安装固定点、走线路径，以及底座内 LiPo 电池和香氛容器的预留空间 |
| 装配间隙验证 | PCB 最终尺寸确认后核查各部件间隙；补充 USB-C 开口和 PCB 固定方式 |
| 高保真外观 | 3D 打印母模 → 树脂翻模，获得光滑表面；目标透明上壳 + 白色底座（暂定） |
| LED 灯效 | 评估内置 LED 灯带方案，通过外壳壁呈现呼吸灯交互状态 |
| 香氛瓶 | 选配尺寸与内筒直径匹配的香氛瓶 |

## 4. PCB 设计 v1

### 设计方案

由于所有元件均为成品开发板，PCB 以 **JST 接插件封装**作为接口，无需直接焊接元件。板上集成：

- XIAO ESP32-S3
- BME680 开发板
- INMP441 麦克风开发板
- PIR 传感器接口
- 雾化片 MOSFET 驱动电路
- MT3608 升压转换器（封装从零绘制）
- LiPo 电池接口

PCB 为**圆形，半径 45 mm**，与圆柱形外壳底座匹配。

PCB v1 原理图 — 所有开发板通过 JST 接插件连接 PCB v1 原理图

PCB v1 KiCAD 布线图 — 圆形板 R=45mm，JST 接插件封装 PCB v1 PCB 布线

### 制作

PCB 在 **GIX 使用 LPKF PCB 铣床**完成打样。铣切结果确认圆形板可放入外壳底座，同时直观呈现了走线质量和接口间距。

PCB v1 LPKF 铣切完成 PCB v1 在 GIX LPKF 铣床打样完成，已裁切，等待焊接

PCB v1 部分焊接中 PCB v1 部分焊接 — 各子系统通电测试进行中

**当前状态：** 板已裁切，部分焊接完成。下一步对 PCB 上各子系统进行功能测试，随后根据发现的间距或走线问题进行第二版修订，再进行整机组装。

## 下一步计划

| 完成 | 任务 | 说明 |
|:-:|---|---|
| <input type="checkbox" /> | **PCB 最终焊接与测试** | 完成 PCB v1 通电测试，LiPo + MT3608 供电，验证 GPIO 接线，确认无短路。根据问题打样并焊接 PCB v2。 |
| <input type="checkbox" /> | **外壳上盖** | 以硅胶模具翻模透明树脂上盖。PLA 母模的层纹天然形成磨砂质感。 |
| <input type="checkbox" /> | **外壳下底座** | 完成建模与切片，SLA 打印；需与上盖卡扣精确对齐。 |
| <input type="checkbox" /> | **整机系统集成测试** | 所有传感器 + ML + Firebase + 应用同时运行，在真实条件下验证完整流程。 |

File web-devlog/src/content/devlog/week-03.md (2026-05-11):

---
week: 3
date: "April 14 - April 20, 2026"
title: "Voice, Firebase & PIR — Build Log"
status: "Completed"
show_next_steps: true
summary: >
  Yutong validated PSRAM and the SPH0645 microphone, built the full ESP-SR
  voice recognition pipeline with a wake-word state machine and a real-time
  serial monitor, integrated Firebase Realtime Database with a cloud dashboard,
  and updated the KiCAD schematic to v2.0. Lucia wired the HC-SR501 PIR sensor
  to presence-trigger the ultrasonic atomizer, prepared the Milestone 1 slides,
  and submitted the budget update form. The BME680 VOC sensor remains in transit.
credits:
  - name: Lucia
    initials: L
    tags:
      - PIR Sensor
      - Milestone Slides
      - Budget Update Form
  - name: Yutong
    initials: Y
    tags:
      - Voice Recognition
      - Firebase
      - Schematic Update
      - Devlog
prior_week_progress:
  refine-cad-schematic: true
  wifi-firebase: true
  microphone-module: true
  atomizer-test: true
planned_next:
  - id: end-to-end-integration
    label: PIR + Atomizer + Firebase End-to-End
    description: "Highest priority: merge the two validated paths — PIR trigger → atomizer spray → Firebase event write — completing the first full closed-loop pipeline."
  - id: unified-state-machine
    label: Voice + PIR Unified State Machine
    description: Merge voice commands and PIR triggers into a single state machine with defined priority (e.g. voice "stop" can interrupt a PIR-triggered spray) and concurrent conflict handling.
  - id: mobile-app
    label: Mobile App Framework
    description: Build a basic app that connects to Firebase and displays spray event history with timestamps.
  - id: bme680-bring-up
    label: BME680 Bring-up
    description: "If sensor arrives this week: validate I2C, read raw VOC/temperature/humidity, and begin collecting bathroom VOC time-series for the ML dataset."
---

## Executive Summary

Two validated hardware paths, a live cloud pipeline, and the first end-to-end spray cycle.

- **PSRAM & mic validation** — Confirmed 8 MB OPI PSRAM (required for ESP-SR AFE); brought up SPH0645 with energy-based VAD in isolation before integrating the full pipeline.
- **Voice recognition** — Built complete ESP-SR v2.0 pipeline: AFE noise suppression + MultiNet v7 keyword spotter, wake-word state machine ("Aura" → 7 s command window), FreeRTOS dual-core split. Debugged two non-obvious I2S issues (API conflict; DMA interleave).
- **Serial voice monitor** — Real-time Streamlit dashboard (`voice_monitor.py`) streams audio level, recognised commands, and state over USB serial — no user interaction needed.
- **Firebase integration** — Connected ESP32 to Firebase Realtime Database; worked through three authentication approaches before landing on database-secret legacy token. Every "Spray" command writes a timestamped event to `/spray_events`.
- **Cloud dashboard** — `firebase_dashboard.py`: polls Firebase via REST, no SDK, dark/light mode, 5-second auto-refresh, spray history charts.
- **PIR + atomizer** — Lucia wired HC-SR501 through a 2N2222 NPN transistor; first end-to-end presence-triggered spray cycle confirmed.
- **BME680** — Still in transit; bring-up deferred to Week 4.

## Mentor Meeting

*We connected with our project mentor this week.*

His input touched on three areas:

**1 · Whole-home ecosystem integration**
Rather than shipping a standalone device with its own microphone and cloud backend, Justin suggested positioning AuraSync as a **smart-home accessory** — registering with Apple HomeKit, Google Home, or the Matter protocol so it receives commands through the user's existing smart speaker or phone. This approach offloads speech recognition entirely to proven platform APIs (Siri, Google Assistant) and integrates naturally into routines users have already set up.

**2 · Sensor rationalisation**
Justin observed that both the microphone and the BME680 ultimately infer the same high-level events — presence, shower start, odour spike. Since the BME680 provides richer and more distinctive environmental signals, he recommended keeping it and replacing the microphone with a simpler, lower-power **PIR sensor** for presence detection. The microphone's value is largely duplicated once platform voice APIs are in the picture.

**3 · Cloud architecture**
Delegating voice to Apple/Google APIs dissolves the custom cloud pipeline question: the platform handles speech-to-intent; AuraSync only needs to respond to accessory events over a local home network.

**Our response for Milestone 1:** We find the ecosystem direction compelling and intend to explore it after the milestone. For the current demo we are retaining the microphone (already validated and integrated) while also adding the PIR sensor as Justin suggested. We will revisit the microphone-vs-platform trade-off at Milestone 2, informed by real BME680 signal quality data once the sensor arrives.

## 1. Hardware Bring-up, Voice Recognition & Serial Monitor

The build followed a deliberate bottom-up sequence: verify the hardware prerequisite (PSRAM), confirm the microphone works in isolation, then layer the full ESP-SR voice pipeline on top. This way, each step has a clear pass/fail gate before adding the next layer of complexity.

### PSRAM Validation

ESP-SR's AFE (Audio Front End) allocates large audio buffers in PSRAM at initialisation — without PSRAM the AFE crashes immediately. Before committing to the full voice pipeline, we ran `PsramTest.ino` to confirm the hardware prerequisite.

The sketch calls `psramInit()`, checks `psramFound()`, reports total and free heap via `getPsramSize()` / `ESP.getFreePsram()`, and attempts a 512 KB `ps_malloc()` allocation. **Pass condition:** `psramFound()` = YES, allocation succeeds.

> **Result:** 8,386,560 bytes (8 MB) of OPI PSRAM confirmed available — ESP-SR can run.

> **Build note:** Tools → PSRAM must be set to **"OPI PSRAM"** in the Arduino IDE board menu. The default "Disabled" setting makes `psramFound()` return false even though the hardware is present.

---

### Microphone Bring-up

PSRAM confirmed — the next question was whether the microphone itself was producing valid audio. Rather than debug hardware and software simultaneously inside the full ESP-SR pipeline, we wrote a standalone `MicTest.ino` to validate the SPH0645 wiring and audio path first. It uses the legacy `driver/i2s.h` API (simpler for standalone tests; `VoiceTest` switches to the new `i2s_std.h` API required by ESP-SR).

A **DC-blocking high-pass filter** (cutoff ~8 Hz, implemented as a first-order IIR) removes the SPH0645's DC bias before energy estimation. An **energy-based VAD** compares short-term energy (α = 0.03, time constant ~32 ms) against a long-term noise floor (α = 0.001, time constant ~2 s); speech is flagged when STE/LTE > 8× and held for 2 s via the onboard LED.

> **Result:** Microphone confirmed live; VAD reliably separated voice from background noise across the lab bench.

---

### SPH0645 I2S Microphone

Before describing the bring-up results, a note on the hardware itself: the microphone used is not the INMP441 originally in the schematic. The INMP441 originally specified in the schematic was replaced with the **Adafruit SPH0645LM4H breakout** (product #3421). The SPH0645 has **better performance** — higher SNR and a lower noise floor — while sharing an identical I2S pinout. The only wiring difference: SPH0645's SEL pin is tied to GND, selecting the **left channel**.

| Signal | XIAO Pin | GPIO | Notes |
|---|---|---|---|
| BCLK | D8 | 7 | Bit clock |
| LRCL | D9 | 8 | Left/right word select |
| DOUT | D10 | 9 | Serial audio data |
| SEL | GND | — | Left channel select |
| VDD | 3V3 | — | |
| GND | GND | — | |

SPH0645 outputs 18-bit audio left-aligned in bits [31:14] of a 32-bit I2S frame. Firmware reads the full 32-bit word and right-shifts by 14 for peak level, or by 16 for 16-bit PCM to feed the ESP-SR AFE.

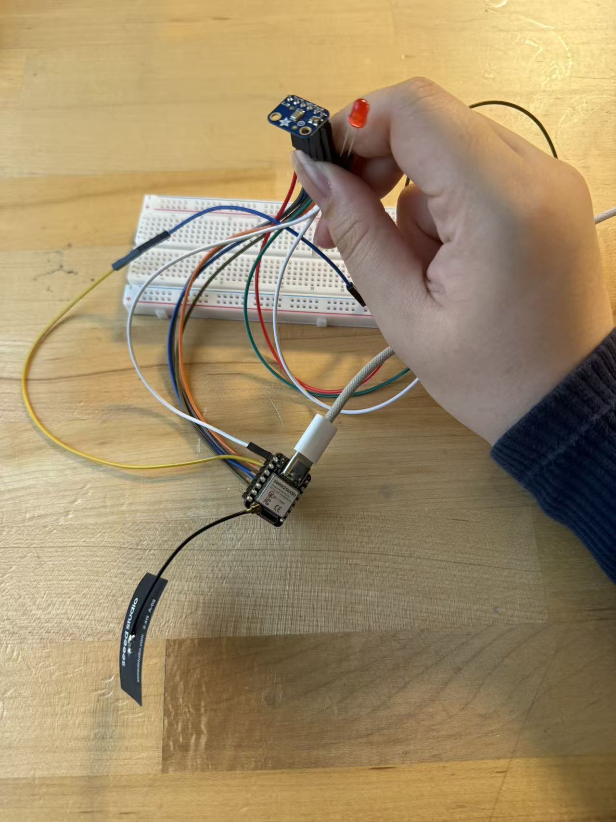
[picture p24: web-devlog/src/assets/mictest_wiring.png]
SPH0645 wiring to XIAO ESP32-S3


---

### ESP-SR Pipeline

With PSRAM confirmed and the microphone producing clean audio, we could move to the actual voice recognition layer. `VoiceTest.ino` integrates both into Espressif's ESP-SR framework to add wake-word detection and command recognition on top of the validated audio path.

**ESP-SR v2.0** (bundled with Arduino ESP32 v3.x, no separate install) provides:
- **AFE** (Audio Front End) — noise suppression + VAD; runs in PSRAM (`AFE_MEMORY_ALLOC_MORE_PSRAM`)
- **MultiNet v7** — English keyword spotter; fires on `ESP_MN_STATE_DETECTED`

Both components run on **FreeRTOS Core 1** (pinned via `xTaskCreatePinnedToCore`), keeping Core 0 free for pump, LED, and Firebase I/O.

**Partition requirement:** The ESP-SR model files live in a dedicated SPIFFS partition. A custom `partitions.csv` (app0 = 3.7 MB, model SPIFFS = 4.25 MB) is placed in the sketch folder alongside a one-time `flash_model.ps1` script that burns the model to flash. Arduino IDE board menu: **"Huge APP (3MB No OTA / 1MB SPIFFS)"**.

**Registered commands:** `aura` (wake word), `spray` (trigger atomizer), `stop`

**I2S API:** The new `driver/i2s_std.h` API (ESP-IDF v5 style) is used throughout — the legacy `driver/i2s.h` conflicts with ESP-SR's internal I2S usage and produces all-zero reads.

### Wake-word State Machine

Recognising short isolated commands at arbitrary moments leads to false positives. We implement a two-stage model: a **wake word** gates a short command window.

The command window is **7 seconds** — 5 s proved too tight because MultiNet only runs during VAD-detected speech segments; silence gaps consume window time without advancing recognition.

LED feedback: "Aura" → slow triple blink; "Spray" → LED on 2 s; "Stop" → LED off immediately.

### Serial Protocol

The firmware streams structured lines for the serial monitor:

| Line | Meaning | Rate |
|---|---|---|
| `LEVEL:xx.x` | Normalised audio amplitude (0–80) | Every DMA frame (~32 ms) |
| `WORD:word:prob` | Recognised command + confidence | On detection |
| `STATE:listening` | Wake word heard, window open | On "Aura" |
| `STATE:idle` | Command executed or window timed out | On transition |

### Challenges

| Symptom | Root cause | Fix |
|---|---|-----|
| All I2S samples returned `0x00000001` | ESP-SR AFE initialises I2S internally via the new driver API; calling the legacy `i2s_driver_install()` after that corrupted the hardware registers | Replaced the entire I2S layer with `i2s_std.h` (`i2s_chan_handle_t`, `i2s_new_channel`, `i2s_channel_read`) |
| Recognition never fired despite audible input | DMA buffer interleaves L/R slots even in MONO config — AFE received L, 0, L, 0, effectively halving the sample rate to 8 kHz and breaking MultiNet's phoneme model | Allocate a 2× buffer, read 2× samples, then extract only even-indexed frames before passing to the AFE |

---

### Serial Voice Monitor

The voice pipeline was now functional, but observing it meant reading raw serial output in the Arduino IDE — a stream of `LEVEL:xx.x`, `WORD:spray:0.87`, and `STATE:listening` lines mixed together and impossible to parse at a glance. We built `monitor/voice_monitor.py` as a live Streamlit dashboard to make the system's state immediately readable during testing.

`monitor/voice_monitor.py` implements a live monitoring interface that requires no user interaction beyond opening the URL.

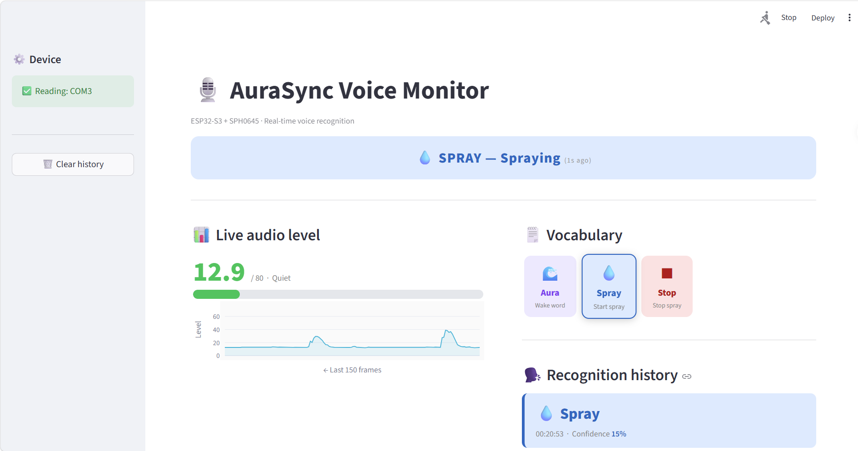
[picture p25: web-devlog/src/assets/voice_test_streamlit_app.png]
AuraSync Voice Monitor — SPRAY state active, live audio level and vocabulary cards


**Architecture:** Uses the `st.empty()` placeholder pattern — a single `while True` loop overwrites placeholder contents each frame without triggering a full Streamlit script rerun.

**Auto-connection:** On startup the app scans available COM ports and connects to the first one found. If the port is held by another process (e.g. Arduino IDE serial monitor), a sidebar error explains the conflict rather than showing silent zeros.

**Panels:**

| Panel | Implementation | Update rate |
|---|---|---|
| State banner | Pure HTML `<div>` | Every frame (0.4 s) |
| Audio level | HTML progress bar + CSS `transition` | Every frame — no flicker |
| Vocabulary cards | HTML — active word highlighted | Every frame |
| Line history | Plotly `go.Scatter` | Every 5 frames (2 s) |
| Recognition cards | HTML — latest command large, history compact | Every frame |
| Word frequency bar | Plotly `go.Bar` | Every 5 frames (2 s) |

The Plotly charts are updated at reduced frequency to avoid the re-render flicker that occurs when a full SVG is replaced each frame.

<video controls muted playsinline style="width:100%;border-radius:0.5rem;margin-bottom:0.75rem">
  <source src="images/devlog/voice_monitor_test.mp4" type="video/mp4" />
</video>

> **Looking ahead:** Once the BME680 arrives, VOC gas resistance becomes a complementary spray trigger — no wake word needed when odour spikes above a learned threshold. Longer-term, delegating voice to Apple HomeKit / Google Home / Matter APIs offloads speech recognition to proven platform infrastructure; AuraSync would only need to respond to accessory events over the local home network.

## 2. Firebase Integration & Cloud Dashboard

### Why Firebase

The voice pipeline was fully functional, but every spray event existed only in RAM — once the board was unplugged or reset, the data was gone. The serial monitor also required a physical USB cable to observe anything. To prove the data pipeline end-to-end and make events accessible remotely, the next step was adding persistent cloud storage.

We chose **Firebase Realtime Database** because it is REST-accessible from any device, requires no custom server, and the free Spark tier is sufficient for a demo. It is REST-accessible from any device, requires no custom server, and the free Spark tier is sufficient for a demo.

### Firmware Architecture

**Library:** `Firebase_ESP_Client` by Mobizt (Arduino Library Manager).

The voice recognition SR task runs on Core 1 and writes command IDs to a **FreeRTOS queue** (depth 8). `loop()` on Core 0 drains the queue and calls `pushSprayEvent()` → `Firebase.RTDB.pushJSON()`. The voice pipeline never blocks on network I/O.

### Partition Challenge

`VoiceTest.ino` alone compiles to ~1.5 MB; the Firebase client library adds ~800 KB, pushing the total to ~2.3 MB — exceeding the default 2 MB app partition.

**Error:** `"text section exceeds available space in device"` at link time.

**Fix:** The same custom `partitions.csv` used for VoiceTest (app0 = 3.7 MB) plus **Tools → Partition Scheme → "Huge APP"** in the Arduino IDE. Both changes are required simultaneously: the CSV controls the flash layout; the IDE menu controls the linker's size check.

### Authentication Journey

Getting the ESP32 authenticated took three attempts:

**Attempt 1 — Anonymous sign-in.** `Firebase.signUp("","")` creates a new anonymous user on every reboot. After a few test runs, 8+ anonymous accounts had accumulated in the Firebase Console. Dropped.

**Attempt 2 — Email/password fixed account.** Switching to a fixed test account hit `PASSWORD_LOGIN_DISABLED` (the Email/Password provider was not yet enabled in the Console). After enabling it, the next error was `INVALID_LOGIN_CREDENTIALS` — a password mismatch between the code and what had been typed in the Console.

**Attempt 3 — Database secret (legacy token).** Setting `fbConfig.signer.tokens.legacy_token` to the project's database secret bypasses GITKit authentication entirely. It works immediately, requires no user management, and is the correct pattern for an IoT device (not a human client).

> **Key takeaway:** IoT devices should not authenticate as human users. A database secret (or a service-account key with restricted rules) is the right primitive — no session management, no password rotation, no anonymous user accumulation.

### Event Schema

Each spray event pushed to `/spray_events/<Firebase push ID>`:

```json
{
  "command": "spray",
  "unixMs": 1776658120000,
  "iso": "2026-04-19T21:08:40Z"
}
```

> **End-to-end demo:** Say **"Aura"** → say **"Spray"** within the 7-second window → LED lights, atomizer fires, and a new record appears in the Firebase Console in real time.

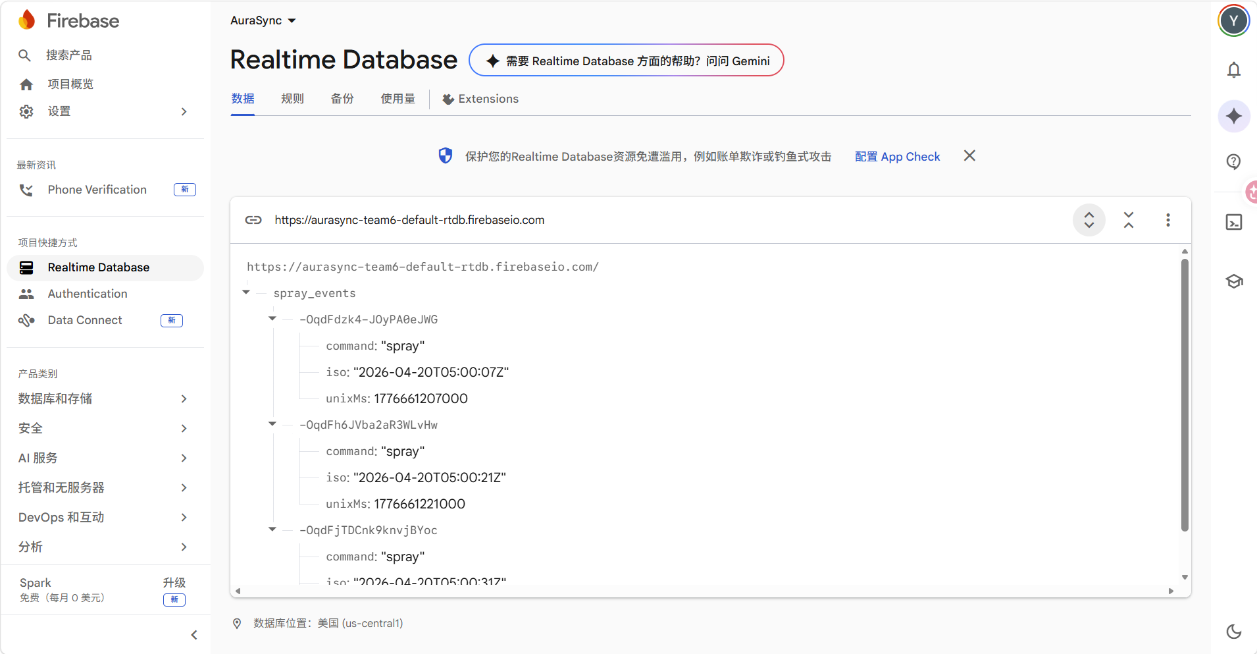
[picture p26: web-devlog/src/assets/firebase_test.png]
Firebase Realtime Database — spray_events with push IDs, command, iso timestamp, and unixMs


### Cloud Dashboard

With events persisting in Firebase, the last piece was a way to view them without opening the Firebase Console. We wanted the same zero-friction experience as the serial monitor — open a URL, see live data. `monitor/firebase_dashboard.py` is a Streamlit app that pulls spray events from Firebase via REST and displays them without needing a USB connection.

**Data access:** Plain `requests.get(f"{DATABASE_URL}/spray_events.json?auth={DATABASE_SECRET}")` — no Firebase SDK or service-account JSON required. `@st.cache_data(ttl=5)` caches the response for 5 seconds; `st.rerun()` drives the auto-refresh loop.

**UI features:**
- Dark / light mode toggle via CSS custom properties + `st.session_state`
- 4 metric cards: total events, last spray time, time-since-last, sprays in last 60 min
- Cumulative step chart (area fill) — shows both frequency and total growth over time
- Hourly distribution bar chart
- Recent events list with ago-time badges
- Daily breakdown with proportional progress bars

The cumulative chart was chosen over a raw scatter plot because it simultaneously communicates frequency (slope) and total usage (height).

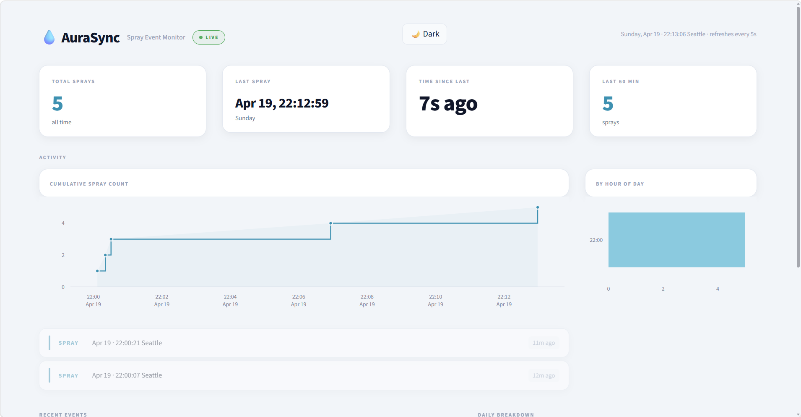
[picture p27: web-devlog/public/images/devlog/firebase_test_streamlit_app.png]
AuraSync Cloud Dashboard — 5 sprays recorded, cumulative chart and hourly breakdown


> **Looking ahead:** **Bi-directional app control** — an app writes `{action:"spray", executed:false}` to `/commands/<pushId>`; the ESP32 polls, executes, then marks `executed:true`. No WebSocket or persistent connection needed. **VOC decay dashboard** — once the BME680 arrives, plot gas resistance with spray markers, compute a "freshness index" (0–100 %, normalised resistance recovery), and estimate re-spray time from a fitted first-order exponential: C(t) = C_max · e^(−k·t).

## 3. PIR Sensor & Presence-Triggered Atomizer

### Hardware

| Component | Model |
|---|---|
| MCU | Seeed Studio XIAO ESP32-S3 |
| Presence sensor | HC-SR501 PIR |
| Atomizer module | SazkJere ultrasonic atomizer + PCB (Micro USB powered) |
| Switching element | 2N2222 NPN transistor |
| Base resistor | 1 kΩ |

### Wiring

| Connection | Notes |
|---|---|
| PIR VCC → XIAO 3V3 | PIR supply |
| PIR GND → GND | Common ground |
| PIR OUT → GPIO4 | Presence signal input |
| GPIO5 → 1 kΩ → 2N2222 Base (middle leg) | Transistor control signal |
| 2N2222 Emitter (left leg) → GND | |
| 2N2222 Collector (right leg) → Atomizer PCB GND | Switches GND return path |
| Atomizer PCB VCC → XIAO 5V | Atomizer power |

*2N2222 orientation — flat face toward you: left = Emitter · middle = Base · right = Collector.*

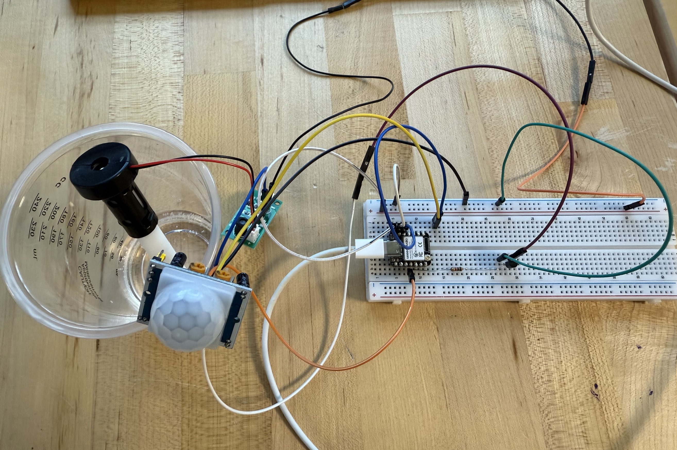
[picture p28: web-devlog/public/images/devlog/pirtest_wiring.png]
HC-SR501 PIR + 2N2222 transistor wiring


### HC-SR501 Configuration

| Control | Setting | Reason |
|---|---|---|
| Sensitivity knob (left) | Minimum (fully CCW) | Reduces detection radius to avoid false triggers across the room |
| Delay knob (right) | Minimum (fully CCW) | Signal returns LOW quickly after person leaves, allowing fast cooldown |
| Jumper | **H** — repeat trigger | Sustains HIGH output continuously while presence remains; **L** (single trigger) caused the output to drop after ~1 s regardless of presence |

### Actuation Logic

The atomizer PCB includes an onboard toggle switch. Because toggling it on every cycle was unreliable, **both switch pads were soldered together (bridged)** so the PCB powers on and begins atomising whenever supply voltage is applied.

### Challenges

| Symptom | Root cause | Fix |
|---|---|-----|
| Atomizer ran constantly at power-up | GPIO logic inverted — HIGH when it should have been LOW | Swapped `HIGH`/`LOW` in firmware |
| PIR went LOW after ~1 s even with continuous presence | Jumper in **L** (single-trigger) mode | Moved jumper to **H** (repeat-trigger) |
| Progress bar reset to 26% repeatedly | Same single-trigger issue — timer cleared before 3 s elapsed | Same fix |
| Atomizer PCB internal switch interfered with control | PCB switch disconnected GND path when in OFF state | Soldered switch pads to permanently bridge |

<video controls muted playsinline style="width:100%;border-radius:0.5rem;margin-bottom:0.75rem">
  <source src="images/devlog/pir_test.mp4" type="video/mp4" />
</video>

## 4. Schematic Update

The KiCAD schematic was updated to **Rev v2.0** to reflect this week's hardware changes:

- **U4 SPH0645\_Mic** replaces the INMP441 — same I2S pin assignments (BCLK → GPIO7, LRCL → GPIO8, DOUT → GPIO9); SEL tied to GND to select the left channel
- **U2 HC-SR501 PIR** added — VCC → 3V3, GND → GND, OUT → GPIO4 (Signal)
- **J2 Battery connector** added as a dedicated 2-pin symbol (BATT+ / BATT−) for the LiPo input
- U1 BME680, U3 MOSFET driver, U5 MT3608 boost, and all power rails remain unchanged from v1.0

AuraSync v2.0 Schematic — SPH0645 mic, HC-SR501 PIR, BME680, MT3608 boost, MOSFET driver, battery connector

*AuraSync v2.0 KiCAD schematic — Rev v2.0, 2026-04-20.*

## 5. Budget Update

| Item | Qty | Unit Price | Total |
|---|-----|---|---|
| Seeed Studio XIAO ESP32-S3 | 2 | $7.49 | $14.98 |
| Adafruit BME680 | 1 | $18.95 | $18.95 |
| Adafruit MOSFET Driver | 1 | $3.95 | $3.95 |
| Mini Water Pump | 4 | $2.36 | $9.43 |
| 3.7V 2000mAh LiPo Battery | 1 | $13.06 | $13.06 |
| INMP441 Microphone Module | 3 | $3.20 | $9.59 |
| Adafruit I2S MEMS Microphone Breakout | 1 | $13.72 | $13.72 |
| DC-DC Step Up Boost Converter | 5 | $1.19 | $5.95 |
| Dupont Jumper Wires (120pcs) | 1 | $6.88 | $6.88 |
| Ultrasonic Mist Maker Ceramics Discs | 6 | $1.17 | $6.99 |
| USB Atomization Drive Circuit Board | 4 | $2.37 | $9.48 |
| **Total Spent** | | | **$113.98** |
| **Total Budget** | | | **$350.00** |
| **Remaining** | | | **$236.02** |

## Next Steps

With both hardware paths validated and the cloud pipeline live, Week 4 shifts from bring-up to integration — merging the two control loops, adding app connectivity, and onboarding the BME680 once it arrives.

| Done | Task | Description |
|:-:|---|---|
| <input type="checkbox" checked /> | **PIR + Atomizer + Firebase End-to-End** | Highest priority — merge the two validated paths: PIR trigger → atomizer spray → Firebase event write. First full closed-loop pipeline. |
| <input type="checkbox" checked /> | **Voice + PIR Unified State Machine** | Merge voice commands and PIR triggers into one state machine with defined priority (e.g. voice "stop" interrupts a PIR-triggered spray) and concurrent conflict handling. |
| <input type="checkbox" checked /> | **Mobile App Framework** | Build a basic app that connects to Firebase and displays spray event history with timestamps. |
| <input type="checkbox" checked /> | **BME680 Bring-up** *(if arrives)* | Validate I2C, read raw VOC / temperature / humidity, and begin collecting bathroom VOC time-series for the ML dataset. |

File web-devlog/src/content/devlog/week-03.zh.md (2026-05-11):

---
week: 3
date: "2026年4月14日 - 4月20日"
title: "语音识别、Firebase 与 PIR——构建日志"
status: "Completed"
show_next_steps: true
summary: >
  Yutong 验证了 PSRAM 和 SPH0645 麦克风，搭建了完整的 ESP-SR 语音识别流水线（包含唤醒词状态机与实时串口监控），接入 Firebase 实时数据库和云端仪表盘，并将 KiCAD 原理图更新至 v2.0。Lucia 为 HC-SR501 PIR 传感器接线，通过存在感触发超声波雾化器，完成里程碑 1 演示幻灯片并提交预算更新表格。BME680 VOC 传感器仍在运输中。
credits:
  - name: Lucia
    initials: L
    tags:
      - PIR 传感器
      - 里程碑幻灯片
      - 预算更新表格
  - name: Yutong
    initials: Y
    tags:
      - 语音识别
      - Firebase 集成
      - 原理图更新
      - 开发日志
prior_week_progress:
  refine-cad-schematic: true
  wifi-firebase: true
  microphone-module: true
  atomizer-test: true
planned_next:
  - id: end-to-end-integration
    label: PIR + 雾化器 + Firebase 端到端集成
    description: "最高优先级：合并两条已验证路径——PIR 触发 → 雾化器喷雾 → Firebase 事件写入——完成首个完整闭环流水线。"
  - id: unified-state-machine
    label: 语音 + PIR 统一状态机
    description: 将语音指令和 PIR 触发合并为单一状态机，定义优先级（例如语音"stop"可中断 PIR 触发的喷雾）并处理并发冲突。
  - id: mobile-app
    label: 移动端应用框架
    description: 构建一个连接 Firebase 的基础应用，展示带时间戳的喷雾事件历史记录。
  - id: bme680-bring-up
    label: BME680 调试
    description: "若本周传感器到货：验证 I2C 通信，读取原始 VOC/温度/湿度数据，并开始采集浴室 VOC 时间序列数据用于机器学习数据集。"
---

## Executive Summary

两条已验证的硬件路径、一条实时云端流水线，以及首次完整的端到端喷雾循环。

- **PSRAM 与麦克风验证** — 确认 8 MB OPI PSRAM（ESP-SR AFE 的必要条件）；在集成完整流水线之前，以独立模式验证 SPH0645 的连线和音频路径。
- **语音识别** — 搭建完整 ESP-SR v2.0 流水线：AFE 噪声抑制 + MultiNet v7 关键词检测器，唤醒词状态机（"Aura" → 7 秒指令窗口），FreeRTOS 双核分配。调试了两个非显而易见的 I2S 问题（API 冲突；DMA 交错）。
- **串口语音监控** — 实时 Streamlit 仪表盘（`voice_monitor.py`）通过 USB 串口流式传输音频电平、已识别指令和系统状态——无需用户交互。
- **Firebase 集成** — 将 ESP32 接入 Firebase 实时数据库；经过三种认证方式的尝试，最终采用数据库密钥（legacy token）方案。每次"Spray"指令向 `/spray_events` 写入带时间戳的事件记录。
- **云端仪表盘** — `firebase_dashboard.py`：通过 REST 轮询 Firebase，无需 SDK，支持深色/浅色模式，5 秒自动刷新，展示喷雾历史图表。
- **PIR + 雾化器** — Lucia 通过 2N2222 NPN 三极管连接 HC-SR501；首次端到端存在感触发喷雾循环确认成功。
- **BME680** — 仍在运输中；调试延至第 4 周。

## Mentor Meeting

*本周我们与项目导师进行了交流。*

导师的反馈涉及三个方面：

**1 · 融入智能家居生态系统**
Justin 建议将 AuraSync 定位为**智能家居配件**——接入 Apple HomeKit、Google Home 或 Matter 协议，通过用户现有的智能音箱或手机接收指令，而非作为独立设备自带麦克风和云端后端。这种方式将语音识别完全交由成熟平台 API（Siri、Google Assistant）处理，并自然融入用户已建立的智能家居场景。

**2 · 传感器精简**
Justin 观察到麦克风和 BME680 最终推断的是相同的高层事件——存在感、淋浴开始、异味峰值。由于 BME680 提供更丰富、更有辨识度的环境信号，他建议保留 BME680，将麦克风替换为更简单、功耗更低的 **PIR 传感器**用于存在感检测。一旦平台语音 API 在场景中发挥作用，麦克风的价值便大为重叠。

**3 · 云端架构**
将语音功能委托给 Apple/Google API 后，自定义云端流水线的问题自然消解：平台负责语音到意图的转换；AuraSync 只需响应本地家庭网络上的配件事件。

**我们在里程碑 1 的回应：** 我们认为融入生态系统的方向很有吸引力，计划在里程碑后探索。当前演示阶段保留麦克风（已验证并集成），同时按 Justin 建议新增 PIR 传感器。我们将在里程碑 2 重新评估麦克风与平台方案的取舍，届时将有真实的 BME680 信号质量数据作为参考。

## 1. 硬件调试、语音识别与串口监控

本次构建遵循自底向上的刻意顺序：先验证硬件前提条件（PSRAM），再确认麦克风独立工作正常，最后在此基础上叠加完整的 ESP-SR 语音流水线。这样，每一步都有清晰的通过/失败判定，然后再增加下一层的复杂度。

### PSRAM 验证

ESP-SR 的 AFE（音频前端）在初始化时会在 PSRAM 中分配大型音频缓冲区——如果没有 PSRAM，AFE 会立即崩溃。在投入完整语音流水线之前，我们运行 `PsramTest.ino` 确认硬件前提条件。

该程序调用 `psramInit()`，检查 `psramFound()`，通过 `getPsramSize()` / `ESP.getFreePsram()` 报告总堆和可用堆，并尝试 512 KB 的 `ps_malloc()` 分配。**通过条件：** `psramFound()` = YES，分配成功。

> **结果：** 确认 8,386,560 字节（8 MB）OPI PSRAM 可用——ESP-SR 可以运行。

> **构建注意：** Arduino IDE 开发板菜单中的 Tools → PSRAM 必须设置为 **"OPI PSRAM"**。默认的"Disabled"设置会使 `psramFound()` 返回 false，即使硬件实际存在。

---

### 麦克风调试

PSRAM 确认后，下一个问题是麦克风本身是否产生有效音频。为了避免同时在完整 ESP-SR 流水线中调试硬件和软件，我们编写了独立的 `MicTest.ino` 先验证 SPH0645 连线和音频路径。该程序使用旧版 `driver/i2s.h` API（独立测试时更简单；`VoiceTest` 切换到 ESP-SR 所需的新 `i2s_std.h` API）。

**直流阻断高通滤波器**（截止频率约 8 Hz，实现为一阶 IIR 滤波器）去除 SPH0645 的直流偏置，再进行能量估算。**基于能量的 VAD** 将短期能量（α = 0.03，时间常数约 32 ms）与长期噪声底（α = 0.001，时间常数约 2 s）对比；当 STE/LTE > 8× 时判定为语音，并通过板载 LED 保持 2 秒。

> **结果：** 麦克风确认正常；VAD 在实验台上可靠区分语音与背景噪声。

---

### SPH0645 I2S 麦克风

在描述调试结果之前，先说明硬件本身：本次使用的麦克风并非原理图中最初指定的 INMP441。INMP441 被替换为 **Adafruit SPH0645LM4H 分线板**（产品编号 #3421）。SPH0645 性能**更优**——更高的信噪比和更低的噪声底——同时共享完全相同的 I2S 引脚定义。唯一的接线差异：SPH0645 的 SEL 引脚接 GND，选择**左声道**。

| 信号 | XIAO 引脚 | GPIO | 说明 |
|---|---|---|---|
| BCLK | D8 | 7 | 位时钟 |
| LRCL | D9 | 8 | 左/右字选择 |
| DOUT | D10 | 9 | 串行音频数据 |
| SEL | GND | — | 左声道选择 |
| VDD | 3V3 | — | |
| GND | GND | — | |

SPH0645 输出 18 位音频，左对齐于 32 位 I2S 帧的 [31:14] 位。固件读取完整 32 位字，右移 14 位获取峰值电平，或右移 16 位获取 16 位 PCM 数据以送入 ESP-SR AFE。

SPH0645 与 XIAO ESP32-S3 的接线图

---

### ESP-SR 流水线

PSRAM 确认且麦克风输出干净音频后，我们进入实际的语音识别层。`VoiceTest.ino` 将两者集成进 Espressif 的 ESP-SR 框架，在已验证的音频路径之上添加唤醒词检测和指令识别。

**ESP-SR v2.0**（随 Arduino ESP32 v3.x 捆绑，无需单独安装）提供：
- **AFE**（音频前端）— 噪声抑制 + VAD；运行于 PSRAM（`AFE_MEMORY_ALLOC_MORE_PSRAM`）
- **MultiNet v7** — 英语关键词检测器；在 `ESP_MN_STATE_DETECTED` 时触发

两个组件均运行于 **FreeRTOS Core 1**（通过 `xTaskCreatePinnedToCore` 固定），Core 0 留给水泵、LED 和 Firebase I/O。

**分区要求：** ESP-SR 模型文件存放在专用 SPIFFS 分区。自定义 `partitions.csv`（app0 = 3.7 MB，model SPIFFS = 4.25 MB）放置于草图文件夹中，配合一次性 `flash_model.ps1` 脚本将模型烧录到 Flash。Arduino IDE 开发板菜单选择：**"Huge APP (3MB No OTA / 1MB SPIFFS)"**。

**注册指令：** `aura`（唤醒词）、`spray`（触发雾化器）、`stop`

**I2S API：** 全程使用新版 `driver/i2s_std.h` API（ESP-IDF v5 风格）——旧版 `driver/i2s.h` 与 ESP-SR 的内部 I2S 使用冲突，会导致全零读取。

### 唤醒词状态机

在任意时刻识别短小的孤立指令容易产生误识别。我们实现了两阶段模型：**唤醒词**控制一个短暂的指令窗口。

指令窗口为 **7 秒**——5 秒被证明太短，因为 MultiNet 仅在 VAD 检测到语音时运行；静默间隔消耗窗口时间却不推进识别。

LED 反馈：听到"Aura"→ 缓慢三次闪烁；"Spray"→ LED 亮 2 秒；"Stop"→ LED 立即熄灭。

### 串口协议

固件向串口监控器流式输出结构化数据行：

| 数据行 | 含义 | 频率 |
|---|---|---|
| `LEVEL:xx.x` | 归一化音频幅度（0–80） | 每个 DMA 帧（约 32 ms） |
| `WORD:word:prob` | 已识别指令 + 置信度 | 检测时输出 |
| `STATE:listening` | 听到唤醒词，指令窗口开启 | "Aura"触发时 |
| `STATE:idle` | 指令执行完毕或窗口超时 | 状态转换时 |

### 遇到的挑战

| 症状 | 根本原因 | 解决方案 |
|---|---|---|
| 所有 I2S 采样返回 `0x00000001` | ESP-SR AFE 通过新版驱动 API 在内部初始化 I2S；之后调用旧版 `i2s_driver_install()` 损坏了硬件寄存器 | 将整个 I2S 层替换为 `i2s_std.h`（`i2s_chan_handle_t`、`i2s_new_channel`、`i2s_channel_read`） |
| 尽管有音频输入，识别从未触发 | 即使在 MONO 配置下，DMA 缓冲区也会交错 L/R 槽——AFE 接收到 L、0、L、0，有效采样率降至 8 kHz，破坏了 MultiNet 的音素模型 | 分配 2× 缓冲区，读取 2× 采样，再提取偶数索引帧传递给 AFE |

---

### 串口语音监控

语音流水线功能已完备，但观察系统运行状态需要在 Arduino IDE 中读取原始串口输出——`LEVEL:xx.x`、`WORD:spray:0.87`、`STATE:listening` 等数据行混杂在一起，无法一眼读懂。为使系统状态在测试中一目了然，我们构建了 `monitor/voice_monitor.py` 作为实时 Streamlit 仪表盘。

`monitor/voice_monitor.py` 实现了一个实时监控界面，用户只需打开 URL，无需任何交互操作。

AuraSync 语音监控——SPRAY 状态激活，实时音频电平与词汇卡片

**架构：** 使用 `st.empty()` 占位符模式——单个 `while True` 循环每帧覆盖占位符内容，无需触发完整的 Streamlit 脚本重新运行。

**自动连接：** 启动时，应用自动扫描可用的 COM 端口并连接第一个找到的端口。若端口被其他进程占用（如 Arduino IDE 串口监控器），侧边栏会显示说明冲突的错误信息，而非显示无声的零值。

**功能面板：**

| 面板 | 实现方式 | 更新频率 |
|---|---|---|
| 状态横幅 | 纯 HTML `<div>` | 每帧（0.4 秒） |
| 音频电平 | HTML 进度条 + CSS `transition` | 每帧——无闪烁 |
| 词汇卡片 | HTML——当前词高亮 | 每帧 |
| 历史折线图 | Plotly `go.Scatter` | 每 5 帧（2 秒） |
| 识别卡片 | HTML——最新指令大字显示，历史紧凑排列 | 每帧 |
| 词频柱状图 | Plotly `go.Bar` | 每 5 帧（2 秒） |

Plotly 图表以降低的频率更新，以避免每帧替换完整 SVG 时产生的重新渲染闪烁。

<video controls muted playsinline style="width:100%;border-radius:0.5rem;margin-bottom:0.75rem">
  <source src="images/devlog/voice_monitor_test.mp4" type="video/mp4" />
</video>

> **展望未来：** BME680 到货后，VOC 气体阻抗将成为补充触发器——无需唤醒词，当气味超过学习阈值时直接触发喷雾。长远来看，将语音功能委托给 Apple HomeKit / Google Home / Matter API 可将语音识别转交成熟平台基础设施；AuraSync 只需响应本地家庭网络上的配件事件。

## 2. Firebase 集成与云端仪表盘

### 为什么选择 Firebase

语音流水线已完全正常运行，但每次喷雾事件仅存在于 RAM 中——拔掉电源或重启后数据即消失。串口监控也需要 USB 物理连接才能观察。为了证明数据流水线的端到端可行性，并使事件可远程访问，下一步是添加持久化云端存储。

我们选择 **Firebase 实时数据库**，因为它可通过 REST 从任何设备访问，无需自定义服务器，而且免费 Spark 套餐足以支撑演示。

### 固件架构

**库：** Mobizt 的 `Firebase_ESP_Client`（Arduino Library Manager）。

语音识别 SR 任务运行于 Core 1，将指令 ID 写入 **FreeRTOS 队列**（深度 8）。Core 0 的 `loop()` 负责消耗队列并调用 `pushSprayEvent()` → `Firebase.RTDB.pushJSON()`。语音流水线不会因网络 I/O 而阻塞。

### 分区挑战

`VoiceTest.ino` 单独编译约 1.5 MB；Firebase 客户端库增加约 800 KB，总计约 2.3 MB——超出了默认 2 MB 的 app 分区。

**报错：** `"text section exceeds available space in device"`（链接时）。

**解决方案：** 使用与 VoiceTest 相同的自定义 `partitions.csv`（app0 = 3.7 MB），同时在 Arduino IDE 中选择 **Tools → Partition Scheme → "Huge APP"**。两项更改必须同时进行：CSV 控制 Flash 布局；IDE 菜单控制链接器的大小检查。

### 认证历程

让 ESP32 通过认证经历了三次尝试：

**尝试一 — 匿名登录。** `Firebase.signUp("","")` 每次重启都创建新的匿名用户。几次测试后，Firebase Console 中已积累了 8+ 个匿名账户。放弃。

**尝试二 — 邮箱/密码固定账户。** 切换到固定测试账户后遇到 `PASSWORD_LOGIN_DISABLED`（Console 中邮箱/密码提供商尚未启用）。启用后，下一个错误是 `INVALID_LOGIN_CREDENTIALS`——代码中的密码与 Console 中输入的不匹配。

**尝试三 — 数据库密钥（legacy token）。** 将 `fbConfig.signer.tokens.legacy_token` 设置为项目的数据库密钥，完全绕过 GITKit 认证。该方式即时生效，无需用户管理，是 IoT 设备（而非人类客户端）的正确模式。

> **核心启示：** IoT 设备不应以人类用户身份认证。数据库密钥（或具有受限规则的服务账户密钥）才是正确的原语——无会话管理、无密码轮换、无匿名用户积累。

### 事件数据结构

每次喷雾事件推送至 `/spray_events/<Firebase push ID>`：

```json
{
  "command": "spray",
  "unixMs": 1776658120000,
  "iso": "2026-04-19T21:08:40Z"
}
```

> **端到端演示：** 说 **"Aura"** → 在 7 秒窗口内说 **"Spray"** → LED 亮起，雾化器触发，Firebase Console 实时出现新记录。

Firebase 实时数据库——spray_events 及 push ID、command、iso 时间戳和 unixMs

### 云端仪表盘

事件持久化到 Firebase 后，最后一块拼图是在不打开 Firebase Console 的情况下查看数据。我们希望与串口监控器同样的零摩擦体验——打开 URL 即可看到实时数据。`monitor/firebase_dashboard.py` 是一个 Streamlit 应用，通过 REST 从 Firebase 拉取喷雾事件并展示，无需 USB 连接。

**数据访问：** 直接使用 `requests.get(f"{DATABASE_URL}/spray_events.json?auth={DATABASE_SECRET}")` —— 无需 Firebase SDK 或服务账户 JSON。`@st.cache_data(ttl=5)` 将响应缓存 5 秒；`st.rerun()` 驱动自动刷新循环。

**UI 功能：**
- 通过 CSS 自定义属性 + `st.session_state` 实现深色/浅色模式切换
- 4 个指标卡片：总事件数、最近喷雾时间、距上次喷雾时长、最近 60 分钟内的喷雾次数
- 累积阶梯图（面积填充）——同时展示频率（斜率）和总用量（高度）
- 每小时分布柱状图
- 带时间徽章的近期事件列表
- 按比例进度条展示的每日细分

累积图的选择优于原始散点图，因为它同时传递了频率（斜率）和总用量（高度）两个维度的信息。

AuraSync 云端仪表盘——5 次喷雾记录，累积图与每小时分布

> **展望未来：** **双向应用控制** — 应用向 `/commands/<pushId>` 写入 `{action:"spray", executed:false}`；ESP32 轮询、执行后标记 `executed:true`，无需 WebSocket 或持久连接。**VOC 衰减仪表盘** — BME680 到货后，绘制带喷雾标记的气体阻抗曲线，计算"清新指数"（0–100%，归一化阻抗恢复率），并通过拟合一阶指数衰减估算再次喷雾时间：C(t) = C_max · e^(−k·t)。

## 3. PIR 传感器与存在感触发雾化器

### 硬件

| 组件 | 型号 |
|---|---|
| 微控制器 | Seeed Studio XIAO ESP32-S3 |
| 存在感传感器 | HC-SR501 PIR |
| 雾化器模块 | SazkJere 超声波雾化器 + PCB（Micro USB 供电） |
| 开关元件 | 2N2222 NPN 三极管 |
| 基极电阻 | 1 kΩ |

### 接线

| 连接 | 说明 |
|---|---|
| PIR VCC → XIAO 3V3 | PIR 电源 |
| PIR GND → GND | 公共地 |
| PIR OUT → GPIO4 | 存在感信号输入 |
| GPIO5 → 1 kΩ → 2N2222 基极（中间引脚） | 三极管控制信号 |
| 2N2222 发射极（左引脚）→ GND | |
| 2N2222 集电极（右引脚）→ 雾化器 PCB GND | 切换 GND 回路 |
| 雾化器 PCB VCC → XIAO 5V | 雾化器电源 |

*2N2222 方向——平面朝向自己：左 = 发射极 · 中 = 基极 · 右 = 集电极。*

HC-SR501 PIR + 2N2222 三极管接线图

### HC-SR501 配置

| 控制 | 设置 | 原因 |
|---|---|---|
| 灵敏度旋钮（左） | 最小（完全逆时针） | 缩小检测范围，避免对面房间误触发 |
| 延迟旋钮（右） | 最小（完全逆时针） | 人离开后信号快速返回 LOW，实现快速冷却 |
| 跳线 | **H** — 重复触发 | 持续有人时保持 HIGH 输出；**L**（单次触发）模式导致输出约 1 秒后下降，无论是否仍有人 |

### 执行逻辑

雾化器 PCB 上有板载拨动开关。由于每次循环手动拨动不可靠，**两个开关焊盘已焊接在一起（短接）**，使 PCB 在施加供电电压时立即上电并开始雾化。

### 遇到的挑战

| 症状 | 根本原因 | 解决方案 |
|---|---|---|
| 上电时雾化器持续运行 | GPIO 逻辑反转——HIGH 时应为 LOW | 交换固件中的 `HIGH`/`LOW` |
| 持续存在时 PIR 约 1 秒后变 LOW | 跳线处于 **L**（单次触发）模式 | 将跳线移至 **H**（重复触发） |
| 进度条反复重置为 26% | 同一单次触发问题——3 秒前计时器已清除 | 同上修复 |
| 雾化器 PCB 内部开关干扰控制 | PCB 开关在 OFF 状态时断开 GND 回路 | 焊接开关焊盘实现永久短接 |

<video controls muted playsinline style="width:100%;border-radius:0.5rem;margin-bottom:0.75rem">
  <source src="images/devlog/pir_test.mp4" type="video/mp4" />
</video>

## 4. 原理图更新

KiCAD 原理图更新至 **Rev v2.0**，以反映本周的硬件变更：

- **U4 SPH0645\_Mic** 替换 INMP441——I2S 引脚分配相同（BCLK → GPIO7、LRCL → GPIO8、DOUT → GPIO9）；SEL 接 GND 选择左声道
- **U2 HC-SR501 PIR** 新增——VCC → 3V3、GND → GND、OUT → GPIO4（Signal）
- **J2 电池连接器** 新增为独立 2 针符号（BATT+ / BATT−）用于锂电池输入
- U1 BME680、U3 MOSFET 驱动、U5 MT3608 升压及所有电源轨从 v1.0 起保持不变

AuraSync v2.0 原理图——SPH0645 麦克风、HC-SR501 PIR、BME680、MT3608 升压、MOSFET 驱动、电池连接器

*AuraSync v2.0 KiCAD 原理图——Rev v2.0，2026-04-20。*

## 5. 预算更新

| 物品 | 数量 | 单价 | 小计 |
|---|-----|---|---|
| Seeed Studio XIAO ESP32-S3 | 2 | $7.49 | $14.98 |
| Adafruit BME680 | 1 | $18.95 | $18.95 |
| Adafruit MOSFET 驱动 | 1 | $3.95 | $3.95 |
| 微型水泵 | 4 | $2.36 | $9.43 |
| 3.7V 2000mAh 锂电池 | 1 | $13.06 | $13.06 |
| INMP441 麦克风模块 | 3 | $3.20 | $9.59 |
| Adafruit I2S MEMS 麦克风分线板 | 1 | $13.72 | $13.72 |
| DC-DC 升压转换器 | 5 | $1.19 | $5.95 |
| 杜邦跳线（120 根装） | 1 | $6.88 | $6.88 |
| 超声波雾化片 | 6 | $1.17 | $6.99 |
| USB 雾化驱动电路板 | 4 | $2.37 | $9.48 |
| **已花费合计** | | | **$113.98** |
| **总预算** | | | **$350.00** |
| **剩余预算** | | | **$236.02** |

## Next Steps

两条硬件路径已验证，云端流水线已运行，第 4 周的重心从调试转向集成——合并两个控制循环、添加应用连接，并在 BME680 到货后进行调试。

| 完成 | 任务 | 说明 |
|:-:|---|---|
| <input type="checkbox" /> | **PIR + 雾化器 + Firebase 端到端集成** | 最高优先级——合并两条已验证路径：PIR 触发 → 雾化器喷雾 → Firebase 事件写入，构建首个完整闭环流水线。 |
| <input type="checkbox" /> | **语音 + PIR 统一状态机** | 将语音指令和 PIR 触发合并为单一状态机，定义优先级（如语音"stop"可中断 PIR 触发的喷雾）并处理并发冲突。 |
| <input type="checkbox" /> | **移动端应用框架** | 构建连接 Firebase 的基础应用，展示带时间戳的喷雾事件历史记录。 |
| <input type="checkbox" /> | **BME680 调试**（如到货） | 验证 I2C 通信，读取原始 VOC/温度/湿度数据，并开始采集浴室 VOC 时间序列数据用于机器学习数据集。 |

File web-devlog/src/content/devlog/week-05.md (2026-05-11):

---
week: 5
date: "April 28 - May 4, 2026"
title: "Data Collection, ML Pipeline, BSEC2 Firmware & App Redesign"
status: "Completed"
show_next_steps: true
summary: >
  The team collected approximately 3 days of continuous BME680 data (16 927
  readings) and built a full end-to-end ML pipeline: a Random Forest IAQ
  classifier (CV Macro F1 0.77 ± 0.17) and a 1D-CNN shower event detector
  (Val F1 0.77, AUC 0.94). A firmware upgrade to Bosch BSEC2 addressed
  multi-day gas-resistance baseline drift. Yutong implemented full
  bi-directional Firebase control — the app commands the ESP32 via a
  JSON message bus, receives acknowledgement via node deletion, and was
  redesigned into an Apple-style smart-home panel with live sensor display,
  cooldown countdown, settings sync, usage stats, and push notifications.
credits:
  - name: Lucia
    initials: L
    tags:
      - Data Collection
      - ML Pipeline
      - BSEC2 Firmware
  - name: Yutong
    initials: Y
    tags:
      - Firebase Reverse Control
      - App Redesign
      - Devlog
prior_week_progress:
  bme680-firmware: true
  voc-pattern-detection: "partial"
  voc-baseline: true
  firebase-reverse: true
planned_next:
  - id: shower-data-and-retrain
    label: Shower Data Collection & CNN Retraining
    description: "Collect 5+ BSEC2 shower sessions with annotated start/end times (≥150 positive windows); retrain 1D-CNN replacing gas_norm with calibrated iaq + iaq_accuracy ≥ 1; target Val F1 ≥ 0.85."
  - id: extreme-case-testing
    label: Extreme Case VOC Testing
    description: "Perfume, air freshener, cooking VOCs — test IAQ spike magnitude, recovery time, and classifier edge cases (compound events, high-humidity baseline days)."
  - id: enclosure
    label: Medium-Fidelity Enclosure
    description: "Design and fabricate a medium-fidelity enclosure housing ESP32-S3, BME680, PIR, atomizer, and battery — untethered form factor required for Milestone 2 demo."
  - id: pcb
    label: PCB Design & Fabrication
    description: "Integrate ESP32-S3, INMP441, BME680, PIR, atomizer MOSFET, MT3608 boost, and LiPo connector onto a single PCB; route traces, verify footprints, send for fabrication."
---

## Mentor Meeting

*We connected with our project mentor Justin again this week.*

Justin gave us five concrete pieces of feedback:

**1 · ML edge-case coverage**
When building ML models, it's important to account for extreme cases that the sensor will encounter in real life — someone entering briefly without using the toilet, back-to-back users, VOC spikes from cleaning products or soap (not odour-related), and the noisy warm-up window right after the device boots. We need a systematic test suite to verify the model does not misfire in these scenarios.

**2 · App remote trigger (pre-spray)**
When no one is in the bathroom, a user should be able to trigger a spray from the app in advance — for example, just before entering. The Firebase reverse-control feature already in our backlog addresses this directly; Justin recommended prioritising it.

**3 · PCB and enclosure co-design**
PCB layout should happen in parallel with enclosure design, not after. Specifically: screw holes and snap-fit points for mounting each sensor, a ventilation opening for the BME680 (it must contact ambient air), PIR field-of-view and angle, and connector/trace positions that are not obscured by the shell walls.

**4 · Smaller PIR sensor**
The HC-SR501 is bulky for a compact enclosure. Justin suggested switching to a smaller module such as the **AM312**, which has a much smaller footprint and is better suited for the final form factor.

> [AM312 Mini Pyroelectric PIR on Amazon](https://www.amazon.com/HiLetgo-Pyroelectric-Sensor-Infrared-Detector/dp/B07RT7MK7C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)

**5 · 3.3 V → 5 V boost converter**
The ultrasonic atomizer requires 5 V, while the ESP32-S3 runs at 3.3 V. Justin suggested evaluating compact boost converter modules. We already have an **MT3608** on hand (already listed in the BOM) — a well-suited choice. He also pointed to the **XL6002** as a compact alternative if we need to integrate the converter directly onto the PCB.

> [XL6002 Boost Converter Module on Amazon](https://www.amazon.com/EC-Buying-XL63020-3-3-XL63020-3-3V-Microcontroller/dp/B0D8T3J8QZ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)

## Executive Summary

Three parallel tracks this week, all centred on closing the loop from raw sensor data to trained models.

- **Data collection** — Lucia deployed the ESP32-S3 + BME680 in a home bathroom and collected 3 days of continuous data: 14 sessions fetched from Firebase, 10 successfully preprocessed (16 927 stable readings at 10 s intervals).
- **ML pipeline** — An end-to-end pipeline was built from raw Firebase data to two trained models: a Random Forest IAQ classifier (CV Macro F1 **0.77 ± 0.17**, 5-fold GroupKFold) and a 1D-CNN shower event detector (Val F1 **0.77**, precision **0.97**, ROC-AUC **0.94**).
- **BSEC2 firmware upgrade** — A critical discovery about gas resistance drift motivated a firmware upgrade to the Bosch BSEC2 library, which outputs a self-calibrating IAQ index (0–500) that handles multi-day baseline drift without manual normalisation.

## 1. Data Collection

The Seeed XIAO ESP32-S3 + BME680 sensor was deployed in a home bathroom and collected approximately **3 days of continuous data** (April 29 – May 2, Seattle time). 14 sessions were fetched from Firebase; 10 passed preprocessing (4 had corrupted NTP timestamps and were discarded), yielding **16 927 stable readings** at 10 s intervals.

| Split | Sessions | Readings | Annotated showers |
|---|---|---|---|
| Train | 6 | 9 184 | 1 |
| Val | 1 | 1 461 | 2 |
| Test | 2 | 6 046 | 0 |

> Sessions are split at the session level, not the reading level, to prevent data leakage across time.

### Deployment

To protect the bare breadboard circuit from bathroom moisture and condensation, the entire assembly was wrapped in **cling film** before each deployment — a quick prototyping solution that proved effective for multi-day unattended operation.

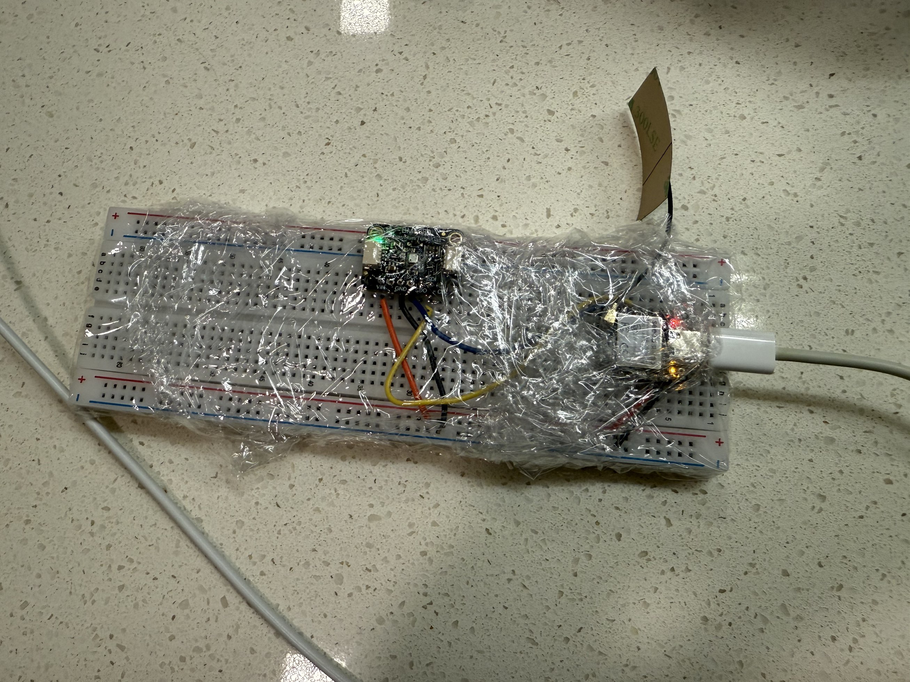
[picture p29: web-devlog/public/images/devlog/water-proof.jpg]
Breadboard with ESP32-S3 and BME680 wrapped in cling film for waterproofing The breadboard assembly wrapped in cling film to protect exposed circuitry from humidity and water vapour during bathroom deployment


Data collection happened in two locations. We first spent an afternoon collecting in the **GIX building bathroom** to get an initial real-world baseline, with a sticky note on the box asking passersby not to disturb the device.

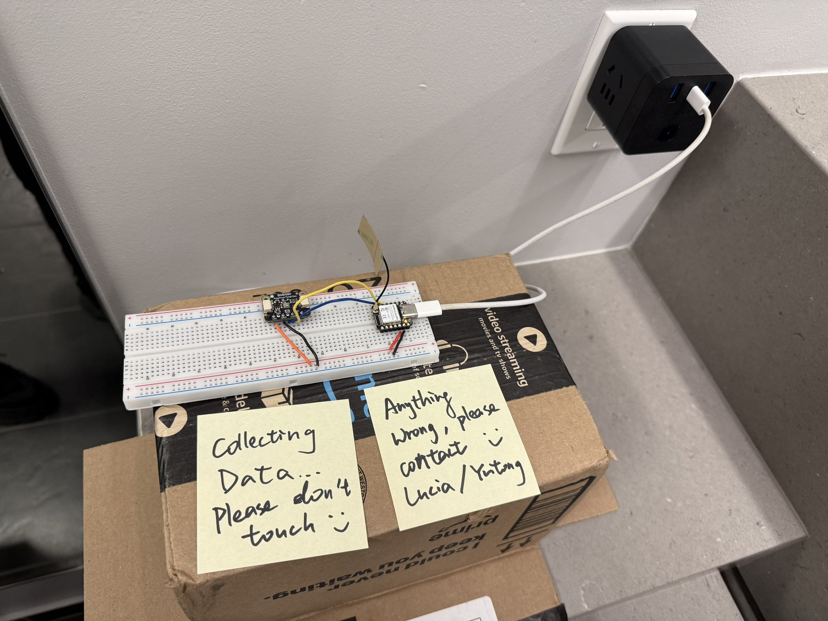
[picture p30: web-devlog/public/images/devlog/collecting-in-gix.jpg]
Sensor deployed in the GIX building bathroom on a cardboard box, with sticky notes reading "Collecting Data — Please don't touch" and "Anything wrong, please contact Lucia / Yutong" First field deployment at GIX — breadboard on a cardboard box on the bathroom counter, with a note to discourage interference


Lucia then brought the device home and ran it continuously for several days, collecting the **bulk of the dataset** with natural VOC variation from daily routines.

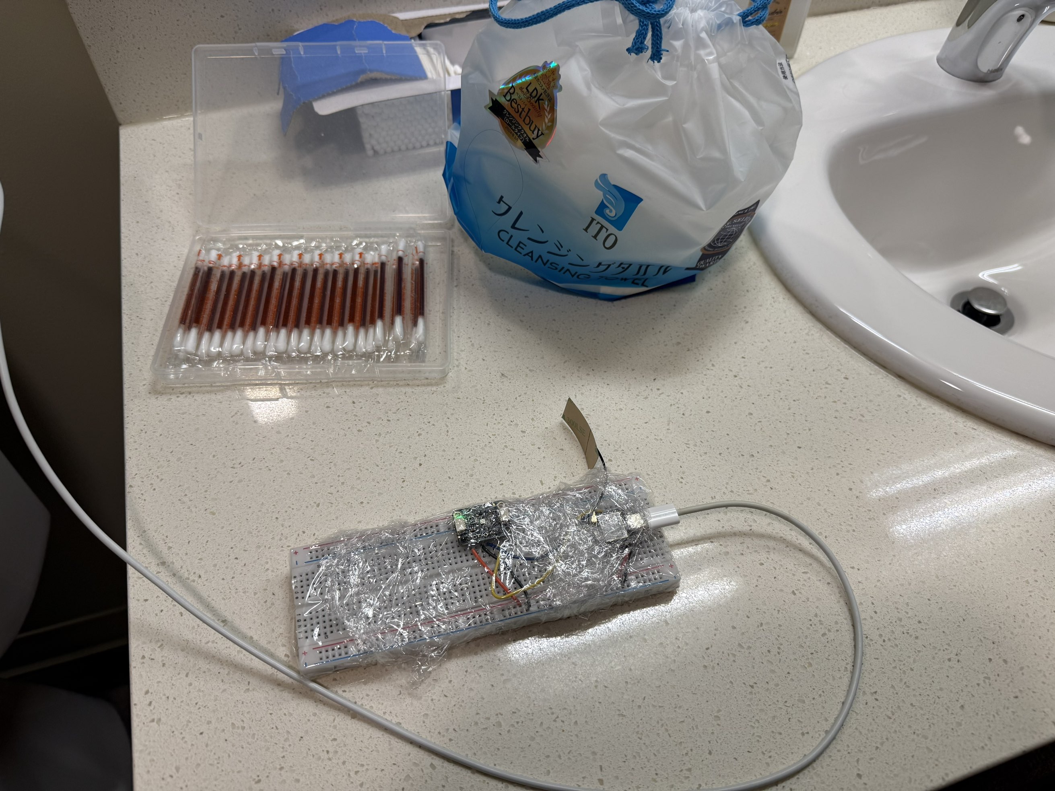
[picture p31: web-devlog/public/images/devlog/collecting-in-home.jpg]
Sensor deployed in home bathroom on the sink counter, with cling-film-wrapped breadboard and USB cable visible Home bathroom deployment — multi-day continuous data collection on the sink counter


Each reading contains: `temp_c`, `humidity_pct`, `pressure_hpa`, `gas_ohm`, `elapsed_s`, `unix_ms`, `iso`, `heater_stable`.

### Key Observation — Gas Baseline Drift

After spraying a strong VOC activator at school, the `gas_ohm` baseline permanently drifted from ~50 kΩ down to ~30 kΩ, then slowly recovered over several days. Using raw gas resistance values as ML features is therefore unreliable across sessions — motivating both the normalisation approach in Phase 2 and the BSEC2 upgrade in Phase 3.

## 2. First ML Pipeline

An end-to-end ML pipeline was built from Firebase data to trained models.

### Data Preprocessing

All sessions were exported from Firebase to CSV via `fetch_firebase.py`. Readings with `heater_stable=False` (first ~120 s per session) were discarded. To handle the gas resistance baseline drift, a **sliding-window baseline normalisation** was applied:

$$\text{gas\_norm}_t = \frac{\text{gas\_ohm}_t - \text{baseline}_t}{\text{baseline}_t}, \quad \text{baseline}_t = \max(\text{gas\_ohm}_{t-120:t})$$

The 20-minute rolling maximum window is long enough to survive shower events without being corrupted. The plot below shows a 9-hour training session: `gas_ohm` drifts upward as the sensor warms over the night, while `gas_norm` stays near zero (clean air) and spikes negative only during actual events.

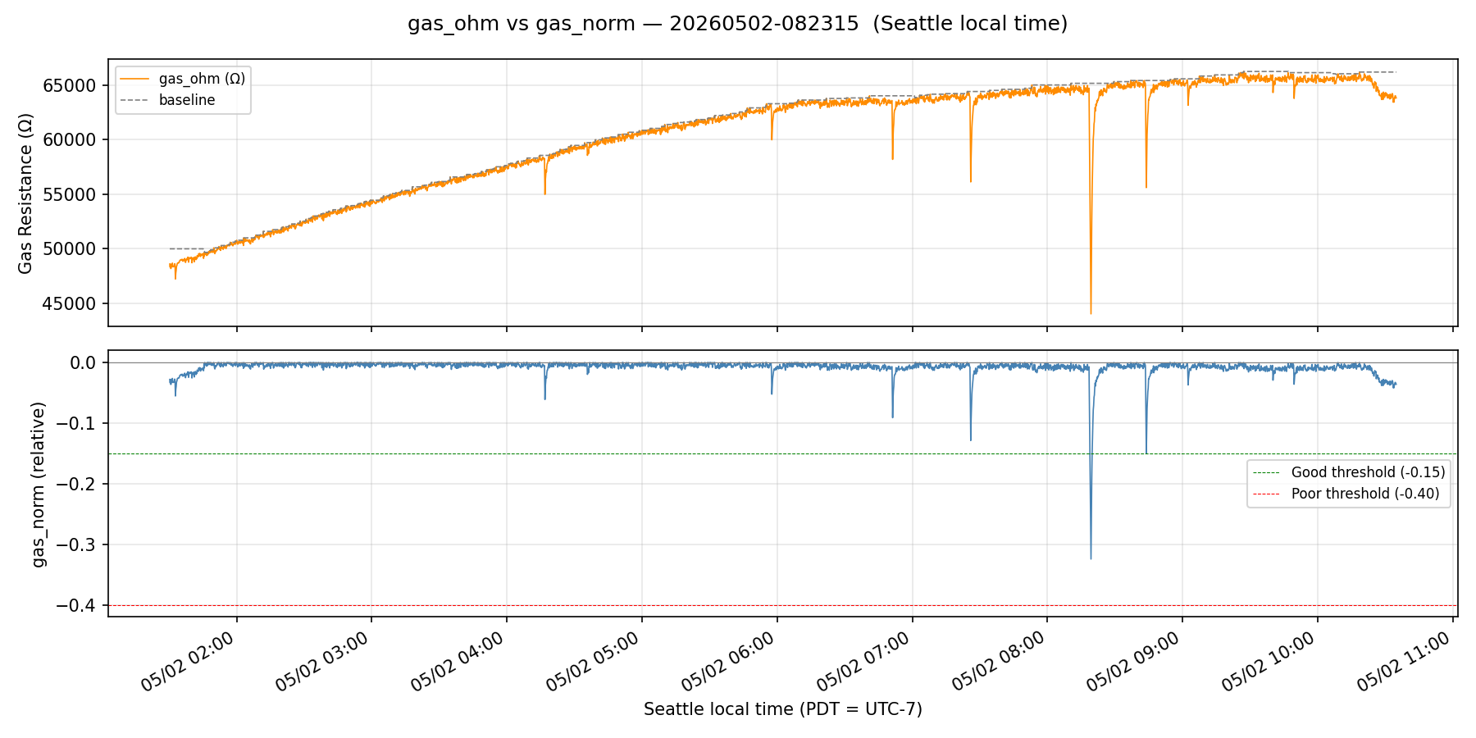
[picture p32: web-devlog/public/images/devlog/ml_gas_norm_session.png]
gas_ohm vs gas_norm for session 20260502-082315 — 9 hours of overnight bathroom data showing how the normalised signal remains stable while raw resistance drifts upward Top: raw gas resistance (Ω) rising as sensor self-calibrates overnight. Bottom: gas_norm baseline-normalised signal, flat near zero between events and spiking negative during odour events


**8 features** were engineered per reading:

| Feature | Description |
|---|---|
| `temp_c` | Raw temperature (°C) |
| `humidity_pct` | Raw humidity (%) |
| `gas_norm` | Baseline-normalised gas resistance (relative) |
| `gas_min_10m` | 10-minute rolling minimum of `gas_norm` |
| `gas_delta_5m` | 5-minute rate-of-change of `gas_norm` |
| `humidity_max_10m` | 10-minute rolling maximum of humidity |
| `humidity_delta_5m` | 5-minute rate-of-change of humidity |
| `temp_delta_5m` | 5-minute rate-of-change of temperature |
| `hour_sin`, `hour_cos` | Cyclical time-of-day encoding |

> The rolling statistics capture trend direction; the sinusoidal time features let the model distinguish morning from evening baseline shifts without treating hour as a linear feature.

**IAQ labels** are assigned by rule (no manual annotation):
- **Good**: `gas_norm > −0.15` AND `humidity < 65 %` AND `temp < 27 °C`
- **Poor**: `gas_norm < −0.40` OR `humidity > 80 %`
- **Moderate**: everything else

Dataset composition: **15 964 Good (96.5 %)** / **473 Moderate (2.9 %)** / **110 Poor (0.7 %)**.

### Task 1 — IAQ Classification (Good / Moderate / Poor)

| | |
|---|---|
| **Model** | Random Forest, `n_estimators=200`, `max_depth=10`, `class_weight='balanced'` |
| **Validation** | 5-fold GroupKFold CV by session — prevents leakage across continuous time |
| **CV Macro F1** | **0.771 ± 0.165** |
| **Test Macro F1** | **0.667** (test sessions had no "Poor" samples) |

The bar chart below shows each fold's Macro F1. Fold 1 reaches 1.0 (the val fold happened to contain balanced classes); Fold 2 scores 0.58 because its val sessions had very few Moderate/Poor readings. GroupKFold variance is expected with such extreme class imbalance.

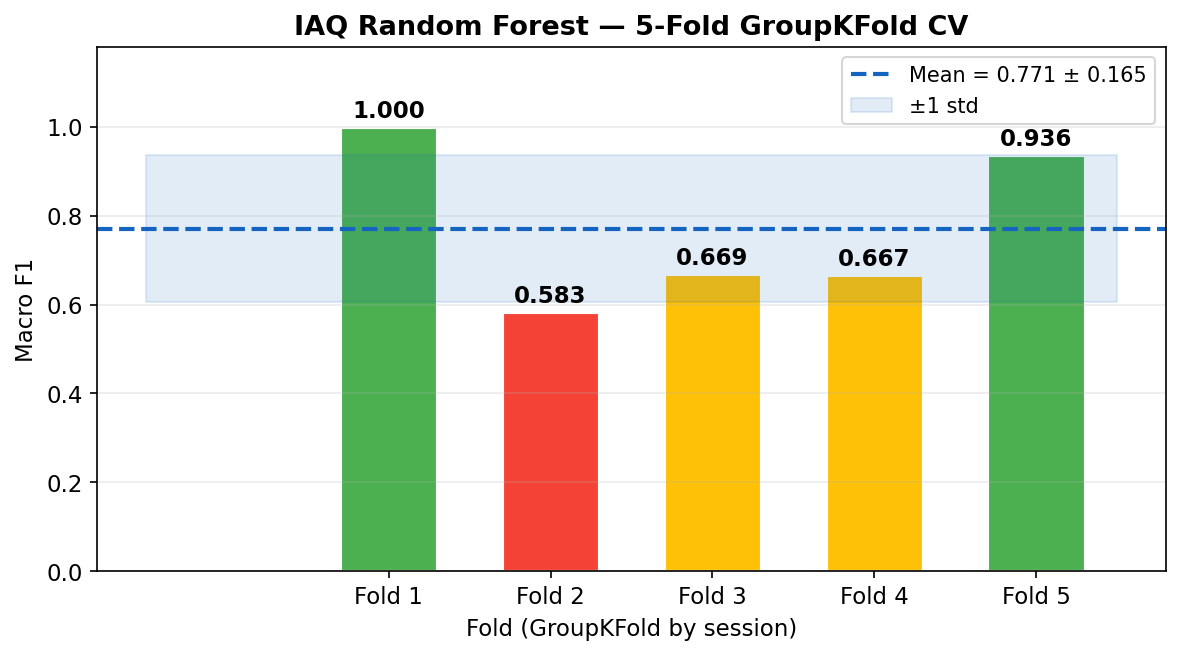
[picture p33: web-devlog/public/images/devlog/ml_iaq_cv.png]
5-fold GroupKFold CV results for IAQ Random Forest — bar chart of per-fold Macro F1 scores with mean and ±1 std band 5-fold GroupKFold cross-validation: F1 = [1.00, 0.58, 0.67, 0.67, 0.94], mean 0.77 ± 0.17


The confusion matrix (test set) shows perfect separation between Good and Moderate — the classifier never confuses the two, though the test set contained no Poor samples.

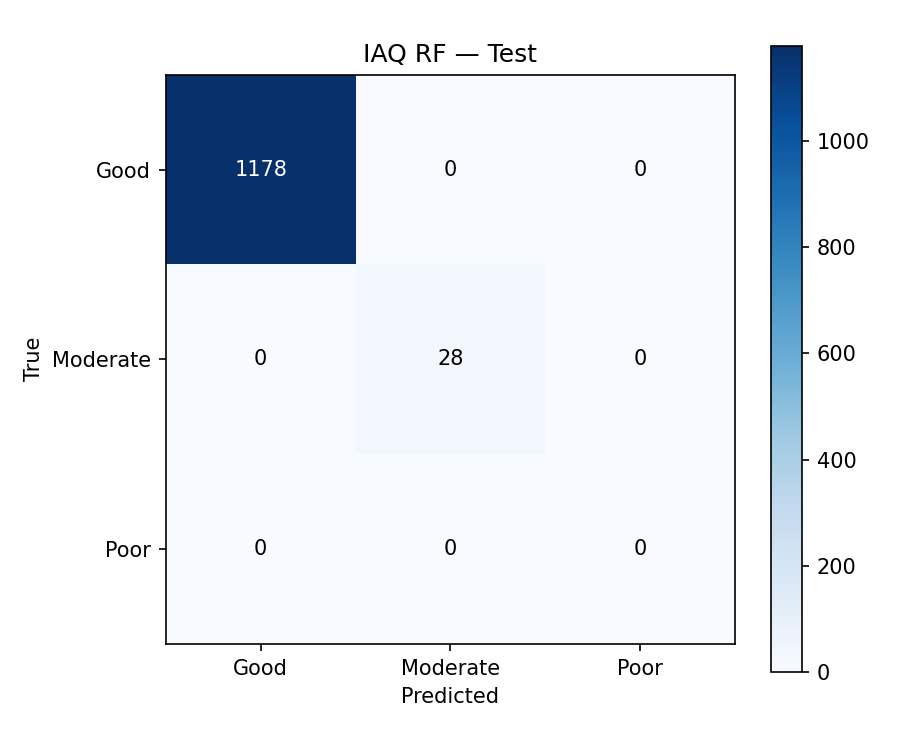
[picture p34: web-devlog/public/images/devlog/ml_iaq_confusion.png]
IAQ Random Forest confusion matrix on the test set — 1178 Good correct, 28 Moderate correct, 0 Poor samples present Test set: 1178 Good correctly classified, 28 Moderate correctly classified. Poor class absent from test sessions.


Feature importance confirms domain knowledge: `gas_norm` accounts for **36 %** of split gain, followed by its rolling statistics (`gas_min_10m`, `gas_delta_5m`). The time-of-day features (`hour_sin`) rank 4th, reflecting the fact that baseline humidity rises predictably in the evenings.

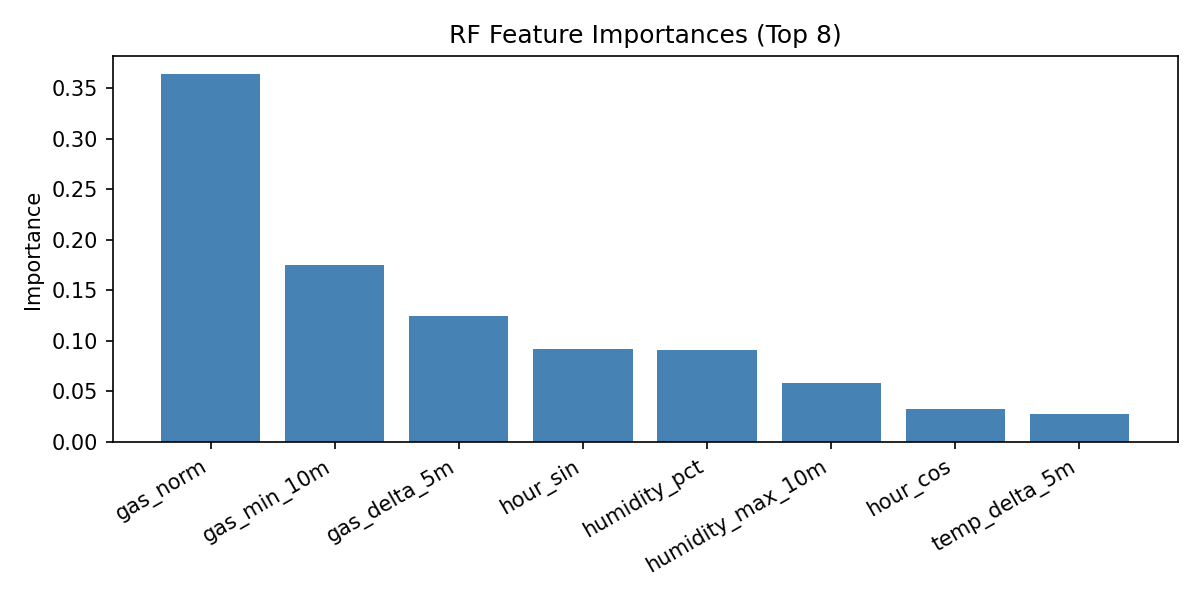
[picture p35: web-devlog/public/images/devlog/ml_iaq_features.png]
RF feature importances (top 8) — gas_norm dominates at 0.36, followed by gas_min_10m at 0.18, gas_delta_5m at 0.12 Top-8 feature importances: gas_norm 0.36 > gas_min_10m 0.18 > gas_delta_5m 0.12 > hour_sin 0.09 > humidity_pct 0.09 > humidity_max_10m 0.06


### Task 2 — Shower Event Detection

**Approach:** sliding-window binary classification — each 5-minute window (30 readings) is classified as shower or not. Stride is 50 s (5 readings), so windows overlap heavily and the detector can flag the start of an event within one stride.

**CNN architecture** (PyTorch, trained on NVIDIA RTX 4060 Laptop GPU):

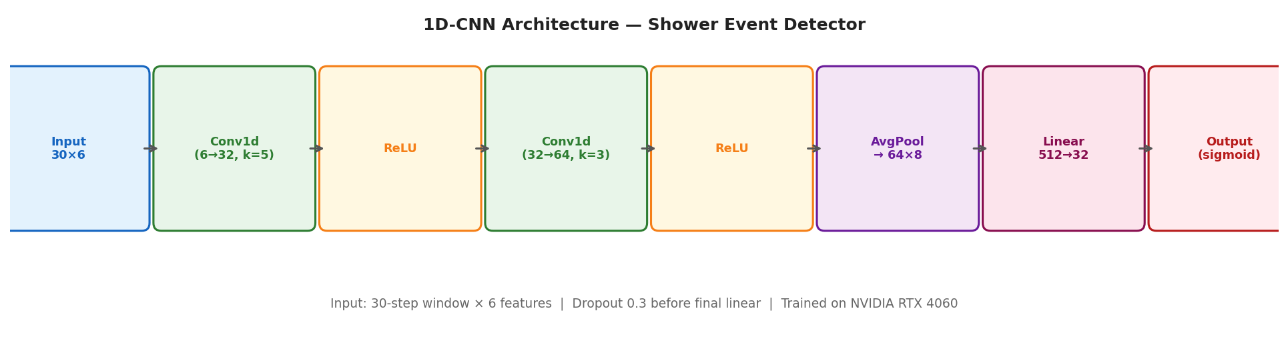
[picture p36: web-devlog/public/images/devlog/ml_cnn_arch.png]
1D-CNN architecture for shower detection — Input 30×6 → Conv1d 6→32 → ReLU → Conv1d 32→64 → ReLU → AdaptiveAvgPool1d → Linear 512→32 → sigmoid output Architecture: Input(30×6) → Conv1d(k=5, 32ch) → Conv1d(k=3, 64ch) → AvgPool(8) → FC(512→32) → FC(32→1, sigmoid). Dropout 0.3 before final layer.


| | Train | Val |
|---|---|---|
| **Total windows** | 1 831 | 285 |
| **Shower (positive)** | 96 | 115 |
| **Non-shower** | 1 735 | 170 |

Training used 4× augmentation on positive windows (Gaussian jitter σ=0.05 + magnitude scaling ±10 %) to partially compensate for the extreme positive class scarcity. The val set has proportionally more shower windows because the annotated val session spans two shower events.

**Results @ threshold = 0.70:**

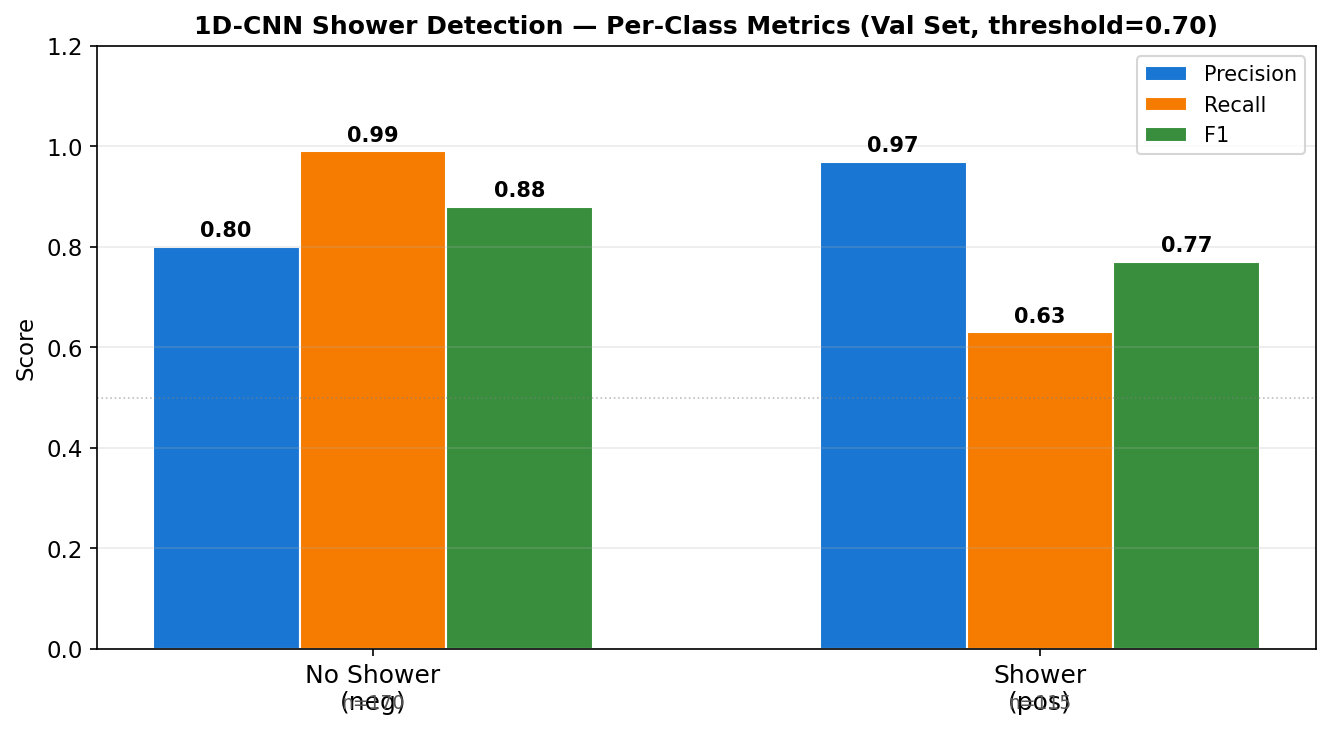
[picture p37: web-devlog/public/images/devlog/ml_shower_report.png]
1D-CNN shower detection per-class precision, recall, and F1 on the val set — Shower precision 0.97, recall 0.63, F1 0.77; No-Shower precision 0.80, recall 0.99, F1 0.88 Val set (285 windows): Shower precision=0.97, recall=0.63, F1=0.77 (n=115). No-Shower precision=0.80, recall=0.99, F1=0.88 (n=170). Accuracy=85%.


The high precision (0.97) means nearly every window the model flags as a shower is a real shower. The lower recall (0.63) means the model misses some shower windows — which is the safer failure mode for our use case (a missed spray is less intrusive than a false spray).

| Metric | Value |
|---|---|
| Val F1 (shower class) | **0.755** |
| Val accuracy | **85 %** |
| ROC-AUC | **0.94** |
| Test F1 | 0.0 (no shower annotations in test sessions — test set is not yet evaluable) |

**Limitation:** only 3 annotated shower events total (96 positive windows before augmentation). The test F1 of 0.0 reflects the absence of shower annotations in the test sessions — a proper generalisation estimate requires collecting and annotating 5+ additional shower sessions.

## 3. BSEC2 Firmware Upgrade

### Problem

The manual 20-minute rolling-max baseline cannot handle multi-day drift. A fundamental fix requires the sensor's baseline to be managed by a proper calibration algorithm at the firmware level.

### Solution: Bosch BSEC2

The firmware was upgraded from the Adafruit BME680 driver to **Bosch-BSEC2-Library** (ESP32-S3 compatible). BSEC2 runs short-term and long-term background calibration models simultaneously, outputting a normalised **IAQ index (0–500)** that is self-calibrating and environment-independent.

### New Firebase Fields

| Field | Description |
|---|---|
| `iaq` | Calibrated IAQ index, 0–500 |
| `iaq_accuracy` | Calibration quality: 0 = unreliable → 3 = fully calibrated |
| `temp_c` | Heat-source compensated temperature |
| `humidity_pct` | Heat-source compensated humidity |

> `static_iaq`, `co2_eq_ppm`, `breath_voc_ppm` require BSEC2 Extended (paid). All three are derived from `gas_ohm` — no independent ML information is lost by omitting them.

### Deployment Challenges

| Issue | Fix |
|---|---|
| `libalgobsec` missing for ESP32-S3 | Switched to Bosch-BSEC2-Library (includes S3 pre-built binary) |
| Linker crash on Chinese username path | Set `build_dir = C:/.pio_build/VOCLogger` in `platformio.ini` |
| `status=14` (unsupported BSEC2 outputs) | Removed Extended-only output fields from the subscription list |
| Serial upload blocks when no PC connected | Added `Serial.setTxTimeoutMs(0)` — non-blocking USB CDC |

### Current Deployment Status

- Sensor deployed in bathroom, uploading every 10 s, running headless on wall power
- Multi-WiFi: automatically tries UW MPSK → home network on connection failure
- BSEC2 calibration state saved to NVS — survives power cuts
- `iaq_accuracy = 0` at cold start; expect ≥ 1 in ~30 min, full calibration (3) in ~4 days

## 4. Firebase Reverse Control & Mobile App

### Bi-directional Command Protocol

The goal: the app sends a spray command to the ESP32 and receives confirmation — without requiring the phone and device to be on the same local network, and without maintaining a persistent WebSocket.

**Solution: Firebase RTDB as a one-shot message bus.** The app writes a command JSON to `/commands/action`; the ESP32 polls every 3 seconds, reads and executes, then calls `deleteNode` to clear the path. Firebase propagates the deletion to the app's `onValue` listener as a `null` snapshot — a lightweight pull-based acknowledgement with roughly 1-second round-trip latency.

```
App  →  /commands/action:
        { action: "spray", source: "app",
          sprayDurationS: 5, requestedAt: 1746354000000 }

ESP32 polls every 3 s  →  reads JSON  →  executes spray
ESP32  →  deleteNode("/commands/action")

App onValue:  snap.val() === null  →  command confirmed ✓
```

**Bug fixed during implementation:** the original `pollFirebaseCommands` used `getString` to read the node (fails silently on a JSON object) and acknowledged by `setString(..., "")` (empty string ≠ `null` — the app checked for `null`). Fixed: `getString` → `getJSON` + `FirebaseJsonData`, acknowledgement → `deleteNode`.

A 10-second timeout on the app side transitions `pending → error` if no acknowledgement arrives, with a 3-second auto-reset to `idle`.

The app command includes a `sprayDurationS` field. The firmware reads this and overrides the atomizer duration for that spray — app-commanded sprays can request any 1–30 s independently of the stored setting.

### Sensor & Status Feedback Paths

To close the feedback loop from device to app, the firmware writes sensor state and cooldown timing to Firebase:

| Path | Written by | Content |
|---|---|---|
| `/sensors/latest` | ESP32 every 5 s | `temp_c`, `humidity_pct`, `gas_ohm`, `heater_ok`, `context`, `updatedAt` |
| `/status/cooldownEndsAt` | ESP32 on state change | Unix ms timestamp when cooldown ends; `0` when idle |
| `/settings/autoSprayEnabled` | App | `true`/`false` — disables P2/P3 sensor triggers firmware-side |
| `/settings/sprayDurationS` | App | Default atomizer on-time (1–30 s); firmware re-reads every 10 s |

### Mobile App Redesign

With the command channel working end-to-end, the app was redesigned from a spray history viewer into a full smart-home control panel, in Apple-style dark and light themes.

**Theme system:** `useColorScheme()` detects system preference. A `ThemeCtx` React Context holds the active palette `C` and a memoised `StyleSheet` `s` — all components call `useTheme()` rather than receiving props. The `StyleSheet` only rebuilds when the colour scheme changes.

**New sections:**

| Section | What it shows |
|---|---|
| **Spray button** | 168 px circular gradient button; dims grey during cooldown; pulses orange while pending |
| **Cooldown bar** | Animated progress bar inside the device card, draining from `/status/cooldownEndsAt` |
| **Sensor card** | Live IAQ quality (gas kΩ, colour-coded Good / Moderate / Poor), temperature, humidity, context badge (Idle / Motion / Spraying / Cooldown) |
| **Settings card** | Auto-spray toggle (Switch → `/settings/autoSprayEnabled`) and duration stepper (− / + buttons, 1–30 s → `/settings/sprayDurationS`) |
| **Usage card** | Today's spray count, trigger-type breakdown (coloured chips), cumulative reservoir estimate (ml remaining out of 30 ml) |
| **Push notifications** | Local notification via `expo-notifications` when Firebase detects a new auto-triggered spray (trigger ≠ `app`) |

## Next Steps

| Done | Task | Description |
|:-:|---|---|
| <input type="checkbox" checked /> | **Shower Data Collection & CNN Retraining** | Collect 5+ BSEC2 shower sessions with annotated start/end times (≥150 positive windows); retrain 1D-CNN replacing `gas_norm` with calibrated `iaq` + `iaq_accuracy ≥ 1`; target Val F1 ≥ 0.85. |
| <input type="checkbox" /> | **Extreme Case VOC Testing** | Perfume, air freshener, cooking VOCs — test IAQ spike magnitude, recovery time, and classifier edge cases. |
| <input type="checkbox" checked /> | **Medium-Fidelity Enclosure** | Design and fabricate a housing for all components (ESP32-S3, BME680, PIR, atomizer, battery) — untethered form factor required for Milestone 2 demo. |
| <input type="checkbox" checked /> | **PCB Design & Fabrication** | Integrate ESP32-S3, INMP441, BME680, PIR, MOSFET, MT3608 boost, and LiPo connector onto a single PCB; route traces, verify footprints, and send for fabrication. |

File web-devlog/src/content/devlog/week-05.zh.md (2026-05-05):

---
week: 5
date: "2026年4月28日 - 5月4日"
title: "数据采集、ML 流水线、BSEC2 固件升级与应用重设计"
status: "In Progress"
show_next_steps: true
summary: >
  团队采集了约 3 天连续 BME680 数据（16 927 条读数），构建了完整端到端 ML 流水线：
  随机森林 IAQ 分类器（CV Macro F1 0.77 ± 0.17）和 1D-CNN 淋浴事件检测器
  （Val F1 0.77，AUC 0.94）。固件升级至 Bosch BSEC2 解决了多日气体阻抗基线漂移问题。
  Yutong 实现了完整的 Firebase 双向控制——应用通过 JSON 消息总线向 ESP32 发送指令，
  通过节点删除确认执行，并将应用重设计为 Apple 风格智能家居面板，
  包含实时传感器显示、冷却倒计时、设置同步、使用统计和推送通知。
credits:
  - name: Lucia
    initials: L
    tags:
      - 数据采集
      - ML 流水线
      - BSEC2 固件
  - name: Yutong
    initials: Y
    tags:
      - Firebase 反向控制
      - 应用重设计
      - 开发日志
prior_week_progress:
  bme680-firmware: true
  voc-pattern-detection: "partial"
  voc-baseline: true
  firebase-reverse: true
planned_next:
  - id: shower-data-and-retrain
    label: 淋浴数据采集与 CNN 重训练
    description: "使用 BSEC2 采集 5 个以上淋浴会话并标注开始/结束时间（≥150 个正样本窗口），随后将 gas_norm 流水线替换为经标定的 iaq + iaq_accuracy ≥ 1 过滤器重训练 1D-CNN；目标 Val F1 ≥ 0.85。"
  - id: extreme-case-testing
    label: 极端 VOC 场景测试
    description: "香水、空气清新剂、烹饪 VOC——测试 IAQ 峰值幅度、恢复时间及分类器边缘情况（复合事件、高湿度基线天）。"
  - id: enclosure
    label: 中保真度外壳
    description: "设计并制作容纳全部元件（ESP32-S3、BME680、PIR、雾化片、电池）的中保真度外壳——Milestone 2 演示所需的无线独立形态。"
  - id: pcb
    label: PCB 设计与制作
    description: "将 ESP32-S3、INMP441、BME680、PIR、雾化 MOSFET、MT3608 升压及 LiPo 接口集成到单块 PCB；完成布线、验证封装、送厂打样。"
---

## Mentor Meeting

*本周与项目导师 Justin 再次进行了会议。*

Justin 给出了五点具体建议：

**1 · ML 边缘情况覆盖**
构建机器学习模型时，需要考虑传感器在真实使用中可能遇到的各种极端情况，例如：有人进入但未如厕（只是拿东西）、多人连续使用、清洁剂或香皂（非如厕来源）引起的 VOC 变化，以及设备刚启动时不稳定的预热读数。需要设计系统性测试，验证模型在这些场景下不会误触发。

**2 · 应用远程提前喷雾**
当无人在卫生间时，用户应能提前通过手机应用触发喷雾——例如进入卫生间之前。我们待办中的 Firebase 反向控制功能正好对应这一需求；Justin 建议优先推进。

**3 · PCB 与外壳协同设计**
PCB 布局应与外壳设计同步进行，而不是事后调整。需提前规划：每个传感器的固定方式（螺丝孔、卡扣位置）、BME680 的通气开口（必须接触环境空气）、PIR 的朝向与视角范围，以及接口和走线位置不被外壳遮挡。

**4 · 换用更小的 PIR 传感器**
HC-SR501 体积较大，不适合紧凑外壳。Justin 建议换用更小的模块，例如 **AM312**，体积小得多，更适合最终产品形态。

> [AM312 迷你热释电 PIR（Amazon 链接）](https://www.amazon.com/HiLetgo-Pyroelectric-Sensor-Infrared-Detector/dp/B07RT7MK7C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)

**5 · 3.3V → 5V 升压方案**
超声波雾化片需要 5V 供电，而 ESP32-S3 工作在 3.3V。Justin 建议评估小型升压模块。我们手头已有 **MT3608**（已在 BOM 中），是非常合适的选择。他还推荐了 **XL6002** 作为紧凑型替代方案，适合直接集成到 PCB 上。

> [XL6002 升压模块（Amazon 链接）](https://www.amazon.com/EC-Buying-XL63020-3-3-XL63020-3-3V-Microcontroller/dp/B0D8T3J8QZ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)

## 执行摘要

本周三条并行主线，均围绕"从原始传感器数据到训练好的模型"这一闭环展开。

- **数据采集** — Lucia 将 ESP32-S3 + BME680 部署在家庭浴室，采集了约 3 天的连续数据：从 Firebase 拉取 14 个会话，10 个通过预处理（16 927 条稳定读数，10 秒间隔）。
- **ML 流水线** — 从原始 Firebase 数据到两个训练完毕的模型：随机森林 IAQ 分类器（CV Macro F1 **0.77 ± 0.17**，5 折 GroupKFold）和 1D-CNN 淋浴事件检测器（Val F1 **0.77**，精确率 **0.97**，ROC-AUC **0.94**）。
- **BSEC2 固件升级** — 气体阻抗漂移的关键发现推动了固件升级至 Bosch BSEC2 库，该库输出自标定 IAQ 指数（0–500），无需手动归一化即可应对多日漂移。

## 1. 数据采集

Seeed XIAO ESP32-S3 + BME680 传感器部署于家庭浴室，采集了约 **3 天的连续数据**（西雅图时间 4 月 29 日–5 月 2 日）。从 Firebase 拉取 14 个会话，10 个预处理成功（4 个因 NTP 时间戳损坏被丢弃），共 **16 927 条稳定读数**，以 10 秒为间隔上传至 Firebase Realtime Database。

| 数据集划分 | 会话数 | 读数数 | 标注淋浴次数 |
|---|---|---|---|
| 训练集 | 6 | 9 184 | 1 |
| 验证集 | 1 | 1 461 | 2 |
| 测试集 | 2 | 6 046 | 0 |

> 数据划分在会话级别进行，而非读数级别，以防止连续时序数据的信息泄露。

### 部署过程

为保护裸露的面包板电路不受浴室水汽和冷凝水的影响，整个电路在每次部署前均用**保鲜膜**进行了包裹处理——这是一种快速的原型保护方案，在多日无人值守运行中被证明切实有效。

ESP32-S3 和 BME680 面包板电路用保鲜膜包裹做防水处理 面包板电路用保鲜膜包裹，保护裸露器件免受浴室湿气和水汽影响

数据采集分两个地点进行。我们首先在 **GIX 楼的卫生间**采集了一个下午的数据，建立初步的真实环境基线，并在箱子上贴上便利贴提示路人勿触碰设备。

传感器部署在 GIX 楼卫生间，放置在纸箱上，便利贴写着"正在采集数据，请勿触碰"和"有问题请联系 Lucia / Yutong" GIX 楼首次实地部署——面包板放在洗手台纸箱上，附有告示便利贴

随后 Lucia 将设备带回家，持续运行数日，采集了**数据集的主体部分**，包含日常生活中自然产生的 VOC 变化。

传感器部署在家庭浴室洗手台上，保鲜膜包裹的面包板和 USB 线清晰可见 家庭浴室部署——多日连续数据采集，设备放置在洗手台上

每条读数包含：`temp_c`、`humidity_pct`、`pressure_hpa`、`gas_ohm`、`elapsed_s`、`unix_ms`、`iso`、`heater_stable`。

### 关键发现——气体基线漂移

在学校喷洒强力 VOC 激活剂后，`gas_ohm` 基线从约 50 kΩ 永久漂移至约 30 kΩ，此后缓慢恢复，历时数日。因此，直接使用原始气体阻抗值作为 ML 特征在跨会话情况下不可靠——这促使了第 2 阶段的归一化方法和第 3 阶段的 BSEC2 升级。

## 2. 首个 ML 流水线

从 Firebase 数据到训练好的模型，构建了完整的端到端 ML 流水线。

### 数据预处理

所有会话通过 `fetch_firebase.py` 从 Firebase 导出为 CSV。`heater_stable=False`（每个会话前约 120 秒）的读数被丢弃。为应对气体阻抗基线漂移，采用了**滑动窗口基线归一化**：

$$\text{gas\_norm}_t = \frac{\text{gas\_ohm}_t - \text{baseline}_t}{\text{baseline}_t}, \quad \text{baseline}_t = \max(\text{gas\_ohm}_{t-120:t})$$

20 分钟滑动最大值窗口足够长，可在淋浴事件期间保持稳定而不被污染。下图展示了一个 9 小时训练会话：`gas_ohm` 在整晚随传感器自校准缓慢上升，而 `gas_norm` 在清洁空气段保持接近零值，仅在真实事件期间出现负值尖峰。

session 20260502-082315 的 gas_ohm 与 gas_norm 对比——9 小时过夜浴室数据，展示归一化信号如何在原始阻抗漂移时保持稳定 上图：原始气体阻抗（Ω）随传感器过夜自校准缓慢上升。下图：gas_norm 基线归一化信号，事件之间接近零值，异味事件期间出现负值尖峰

每条读数共构建 **8 个特征**：

| 特征 | 说明 |
|---|---|
| `temp_c` | 原始温度（°C） |
| `humidity_pct` | 原始湿度（%） |
| `gas_norm` | 基线归一化气体阻抗（相对值） |
| `gas_min_10m` | `gas_norm` 的 10 分钟滚动最小值 |
| `gas_delta_5m` | `gas_norm` 的 5 分钟变化率 |
| `humidity_max_10m` | 湿度的 10 分钟滚动最大值 |
| `humidity_delta_5m` | 湿度的 5 分钟变化率 |
| `temp_delta_5m` | 温度的 5 分钟变化率 |
| `hour_sin`、`hour_cos` | 一天中时刻的循环编码 |

> 滚动统计捕捉趋势方向；正弦/余弦时间特征允许模型区分清晨与傍晚的基线差异，同时避免将小时视为线性特征。

**IAQ 标签**通过规则分配（无手动标注）：
- **Good（良好）**：`gas_norm > −0.15` 且 `humidity < 65 %` 且 `temp < 27 °C`
- **Poor（较差）**：`gas_norm < −0.40` 或 `humidity > 80 %`
- **Moderate（一般）**：其余情况

数据集组成：**15 964 Good（96.5 %）** / **473 Moderate（2.9 %）** / **110 Poor（0.7 %）**。

### 任务一——IAQ 分类（Good / Moderate / Poor）

| | |
|---|---|
| **模型** | 随机森林，`n_estimators=200`，`max_depth=10`，`class_weight='balanced'` |
| **验证方法** | 按会话的 5 折 GroupKFold 交叉验证——防止连续时序数据泄露 |
| **CV Macro F1** | **0.771 ± 0.165** |
| **测试集 Macro F1** | **0.667**（测试会话中无 Poor 样本） |

下图展示各折 Macro F1 的柱状图。第 1 折达到 1.0（验证折恰好包含类别均衡的样本）；第 2 折仅 0.58，因为其验证会话中 Moderate/Poor 读数极少。面对如此严重的类别不平衡，GroupKFold 折间方差属正常现象。

IAQ 随机森林 5 折 GroupKFold 交叉验证结果——各折 Macro F1 柱状图，含均值与 ±1 std 带 5 折 GroupKFold 交叉验证：F1 = [1.00, 0.58, 0.67, 0.67, 0.94]，均值 0.77 ± 0.17

混淆矩阵（测试集）显示 Good 与 Moderate 之间分类完美——分类器从未混淆两者，但测试集中没有 Poor 样本。

IAQ 随机森林测试集混淆矩阵——Good 1178 正确，Moderate 28 正确，Poor 类样本不存在 测试集：1178 个 Good 正确分类，28 个 Moderate 正确分类。Poor 类在测试会话中不存在。

特征重要性验证了领域知识：`gas_norm` 占分裂增益的 **36 %**，其次是滚动统计特征（`gas_min_10m`、`gas_delta_5m`）。时间特征（`hour_sin`）排第 4，反映出傍晚湿度基线的可预测规律性上升。

RF 特征重要性（Top 8）——gas_norm 以 0.36 居首，其次是 gas_min_10m（0.18）和 gas_delta_5m（0.12） Top-8 特征重要性：gas_norm 0.36 > gas_min_10m 0.18 > gas_delta_5m 0.12 > hour_sin 0.09 > humidity_pct 0.09 > humidity_max_10m 0.06

### 任务二——淋浴事件检测

**方法**：滑动窗口二分类——将每个 5 分钟窗口（30 条读数）分类为"淋浴中"或"非淋浴"。步长 50 秒（5 条读数），窗口大量重叠，使检测器能在一个步长内感知事件开始。

**CNN 架构**（PyTorch，在 NVIDIA RTX 4060 Laptop GPU 上训练）：

淋浴检测 1D-CNN 架构图——Input 30×6 → Conv1d 6→32 → ReLU → Conv1d 32→64 → ReLU → AdaptiveAvgPool1d → Linear 512→32 → sigmoid 输出 架构：Input(30×6) → Conv1d(k=5, 32通道) → Conv1d(k=3, 64通道) → AvgPool(8) → FC(512→32) → FC(32→1, sigmoid)。最终层前 Dropout 0.3。

| | 训练集 | 验证集 |
|---|---|---|
| **总窗口数** | 1 831 | 285 |
| **淋浴（正样本）** | 96 | 115 |
| **非淋浴** | 1 735 | 170 |

训练时对正样本窗口进行 4 倍数据增强（高斯抖动 σ=0.05 + 幅度缩放 ±10%），以部分弥补正样本极度稀缺的问题。验证集中淋浴窗口比例相对更高，因为标注的验证会话横跨两个淋浴事件。

**阈值 = 0.70 时的结果：**

1D-CNN 淋浴检测各类别精确率、召回率和 F1——淋浴类精确率 0.97，召回率 0.63，F1 0.77；非淋浴类精确率 0.80，召回率 0.99，F1 0.88 验证集（285 个窗口）：淋浴精确率=0.97，召回率=0.63，F1=0.77（n=115）。非淋浴精确率=0.80，召回率=0.99，F1=0.88（n=170）。准确率=85%。

高精确率（0.97）意味着模型标记为淋浴的窗口几乎全部是真实淋浴。较低的召回率（0.63）意味着模型会遗漏部分淋浴窗口——对于我们的使用场景，这是更安全的失败模式（漏喷比误喷的干扰更小）。

| 指标 | 值 |
|---|---|
| Val F1（淋浴类） | **0.755** |
| Val 准确率 | **85 %** |
| ROC-AUC | **0.94** |
| Test F1 | 0.0（测试会话无淋浴标注，测试集暂无法评估） |

**局限性**：目前仅有 3 个标注淋浴事件（增强前 96 个正样本窗口）。Test F1 为 0.0 反映的是测试会话中缺少淋浴标注，而非模型退化——需要采集并标注 5 个以上淋浴会话才能获得可信的泛化性评估。

## 3. BSEC2 固件升级

### 问题

手动 20 分钟滑动最大值基线无法应对多日漂移。根本解决方案需要在固件层面由专业校准算法管理传感器基线。

### 方案：Bosch BSEC2

固件从 Adafruit BME680 驱动升级至 **Bosch-BSEC2-Library**（兼容 ESP32-S3）。BSEC2 同时运行短期和长期背景校准模型，输出自标定的 **IAQ 指数（0–500）**，环境无关且免手动归一化。

### 新增 Firebase 字段

| 字段 | 说明 |
|---|---|
| `iaq` | 经校准的 IAQ 指数，0–500 |
| `iaq_accuracy` | 校准质量：0 = 不可靠 → 3 = 完全校准 |
| `temp_c` | 热源补偿后温度 |
| `humidity_pct` | 热源补偿后湿度 |

> `static_iaq`、`co2_eq_ppm`、`breath_voc_ppm` 需要 BSEC2 Extended（付费版）。三者均由 `gas_ohm` 派生——省略后 ML 不损失任何独立信息。

### 部署过程中的问题与解决

| 问题 | 解决方案 |
|---|---|
| ESP32-S3 缺少 `libalgobsec` | 切换至 Bosch-BSEC2-Library（内含 S3 预编译二进制） |
| 中文用户名路径导致链接器崩溃 | 在 `platformio.ini` 中设置 `build_dir = C:/.pio_build/VOCLogger` |
| `status=14`（不支持的 BSEC2 输出） | 从订阅列表中移除 Extended 专属输出字段 |
| 无 PC 连接时串口上传阻塞 | 添加 `Serial.setTxTimeoutMs(0)`——非阻塞 USB CDC |

### 当前部署状态

- 传感器已部署于浴室，每 10 秒上传一次，通过外接电源持续无头运行
- 多 WiFi：自动在 UW MPSK → 家庭网络之间切换
- BSEC2 校准状态保存至 NVS——断电后恢复
- 冷启动时 `iaq_accuracy = 0`；约 30 分钟后预计 ≥ 1，约 4 天后达到完全校准（3）

## 4. Firebase 反向控制与应用重设计

### 双向指令协议

目标：应用向 ESP32 发送喷雾指令并获得确认——无需手机和设备在同一局域网，也无需维持持久的 WebSocket 连接。

**方案：以 Firebase RTDB 为一次性消息总线。** 应用向 `/commands/action` 写入 JSON 指令；ESP32 每 3 秒轮询、读取并执行，随后调用 `deleteNode` 清除该路径。Firebase 将删除操作以 `null` 快照的形式传播给应用的 `onValue` 监听器——这是一种轻量级的拉取式确认机制，往返延迟约 1 秒。

```
应用写入  →  /commands/action:
             { action: "spray", source: "app",
               sprayDurationS: 5, requestedAt: 1746354000000 }

ESP32 每 3 s 轮询  →  读取 JSON  →  执行喷雾
ESP32  →  deleteNode("/commands/action")

应用 onValue:  snap.val() === null  →  指令已确认 ✓
```

**开发过程中修复的 Bug：** 原始 `pollFirebaseCommands` 使用 `getString` 读取节点（对 JSON 对象会静默失败）并通过 `setString(..., "")` 确认（设为空字符串 `""` 而非 `null`，但应用检测的是 `null`）。已修正：`getString` → `getJSON` + `FirebaseJsonData`，确认方式 → `deleteNode`。

应用侧设有 10 秒超时，无确认则转为 `pending → error` 状态，3 秒后自动重置为 `idle`。

指令中包含 `sprayDurationS` 字段。固件读取后为该次喷雾覆盖雾化时长——应用触发的喷雾可独立请求 1–30 秒的任意时长，不受存储设置影响。

### 传感器与状态反馈路径

为实现设备到应用的反馈闭环，固件现在将传感器状态和冷却时间写入 Firebase：

| 路径 | 写入方 | 内容 |
|---|---|---|
| `/sensors/latest` | ESP32 每 5 s | `temp_c`、`humidity_pct`、`gas_ohm`、`heater_ok`、`context`、`updatedAt` |
| `/status/cooldownEndsAt` | ESP32 状态变化时 | 冷却结束时的 Unix 毫秒时间戳；空闲时为 `0` |
| `/settings/autoSprayEnabled` | 应用 | `true`/`false`——在固件侧禁用 P2/P3 传感器触发 |
| `/settings/sprayDurationS` | 应用 | 默认雾化时长（1–30 s）；固件每 10 s 重新读取 |

### 移动端应用重设计

双向指令通道跑通后，应用从喷雾历史查看器重设计为完整的智能家居控制面板，采用 Apple 风格的深色/浅色双主题。

**主题系统：** `useColorScheme()` 检测系统偏好。`ThemeCtx` React Context 持有当前色板 `C` 和经 `useMemo` 缓存的 `StyleSheet` `s`——所有组件调用 `useTheme()` 而非接受属性传参。`StyleSheet` 仅在配色方案切换时重建。

**新增 UI 模块：**

| 模块 | 显示内容 |
|---|---|
| **喷雾按钮** | 168 px 圆形渐变按钮；冷却中变灰；待确认时橙色脉动 |
| **冷却倒计时条** | 设备卡片内的动画进度条，根据 `/status/cooldownEndsAt` 倒计 |
| **传感器卡片** | 实时空气质量（气体 kΩ，颜色分级 Good / Moderate / Poor）、温度、湿度、情境标签（空闲 / 运动 / 喷雾中 / 冷却中） |
| **设置卡片** | 自动喷雾开关（Switch → `/settings/autoSprayEnabled`）和时长步进器（− / + 按钮，1–30 s → `/settings/sprayDurationS`） |
| **用量卡片** | 今日喷雾次数、触发类型分类（彩色标签）、累计储液估算（剩余 ml / 30 ml） |
| **推送通知** | 通过 `expo-notifications` 在 Firebase 检测到非应用触发喷雾（trigger ≠ `app`）时发送本地通知 |
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

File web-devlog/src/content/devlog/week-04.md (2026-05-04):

---
week: 4
date: "April 21 - April 27, 2026"
title: "BME680, Unified Firmware & Power-Aware State Machine"
status: "Completed"
show_next_steps: true
summary: >
  Lucia brought up the BME680 VOC/environmental sensor — I2C validated at 0x77,
  all four data streams confirmed live, and a heat-gun test verified real-time
  response. Yutong merged PIR, voice recognition, and Firebase into a single
  AuraSync firmware with a dual-layer state machine, and added WiFi modem sleep
  plus Core 0 throttling for measurable idle power savings. The two-layer state
  machine architecture (SLEEP/AWAKE × IDLE/SPRAYING/COOLDOWN) with a four-priority
  trigger model was co-designed by both; BME680 integration into the live firmware
  remains in progress.
credits:
  - name: Lucia
    initials: L
    tags:
      - BME680 Bring-up
      - State Machine Design
      - Devlog
  - name: Yutong
    initials: Y
    tags:
      - AuraSync Unified Firmware
      - State Machine Design
      - Mobile App
      - Devlog
prior_week_progress:
  end-to-end-integration: true
  unified-state-machine: true
  mobile-app: true
  bme680-bring-up: true
planned_next:
  - id: bme680-firmware
    label: BME680 Firmware Integration
    description: Integrate BME680 into AuraSync alongside PIR and microphone — all three sensors active on a single ESP32-S3 with coordinated sampling.
  - id: voc-pattern-detection
    label: VOC Pattern Detection
    description: Implement sliding-window VOC rise-then-fall detection combined with PIR confirmation to identify post-flush odour events and trigger spray automatically.
  - id: voc-baseline
    label: Real-Environment VOC Baseline
    description: Collect VOC gas resistance time-series in an actual bathroom to calibrate the extreme-odour threshold and train the pattern detector.
  - id: firebase-reverse
    label: Firebase Reverse Control
    description: "Implement app-to-device command channel: app writes to /commands/action; ESP32 polls every 3 s, executes, and clears the node."
---
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

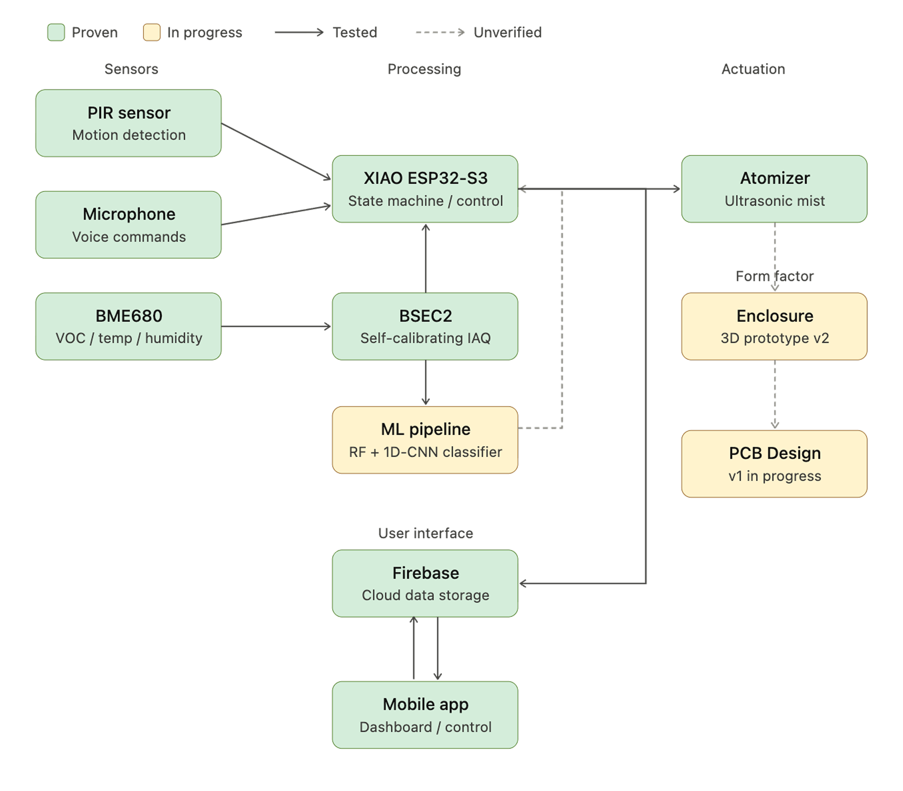
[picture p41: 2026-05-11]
web-devlog/src/assets/milestone_02_archietecture.png

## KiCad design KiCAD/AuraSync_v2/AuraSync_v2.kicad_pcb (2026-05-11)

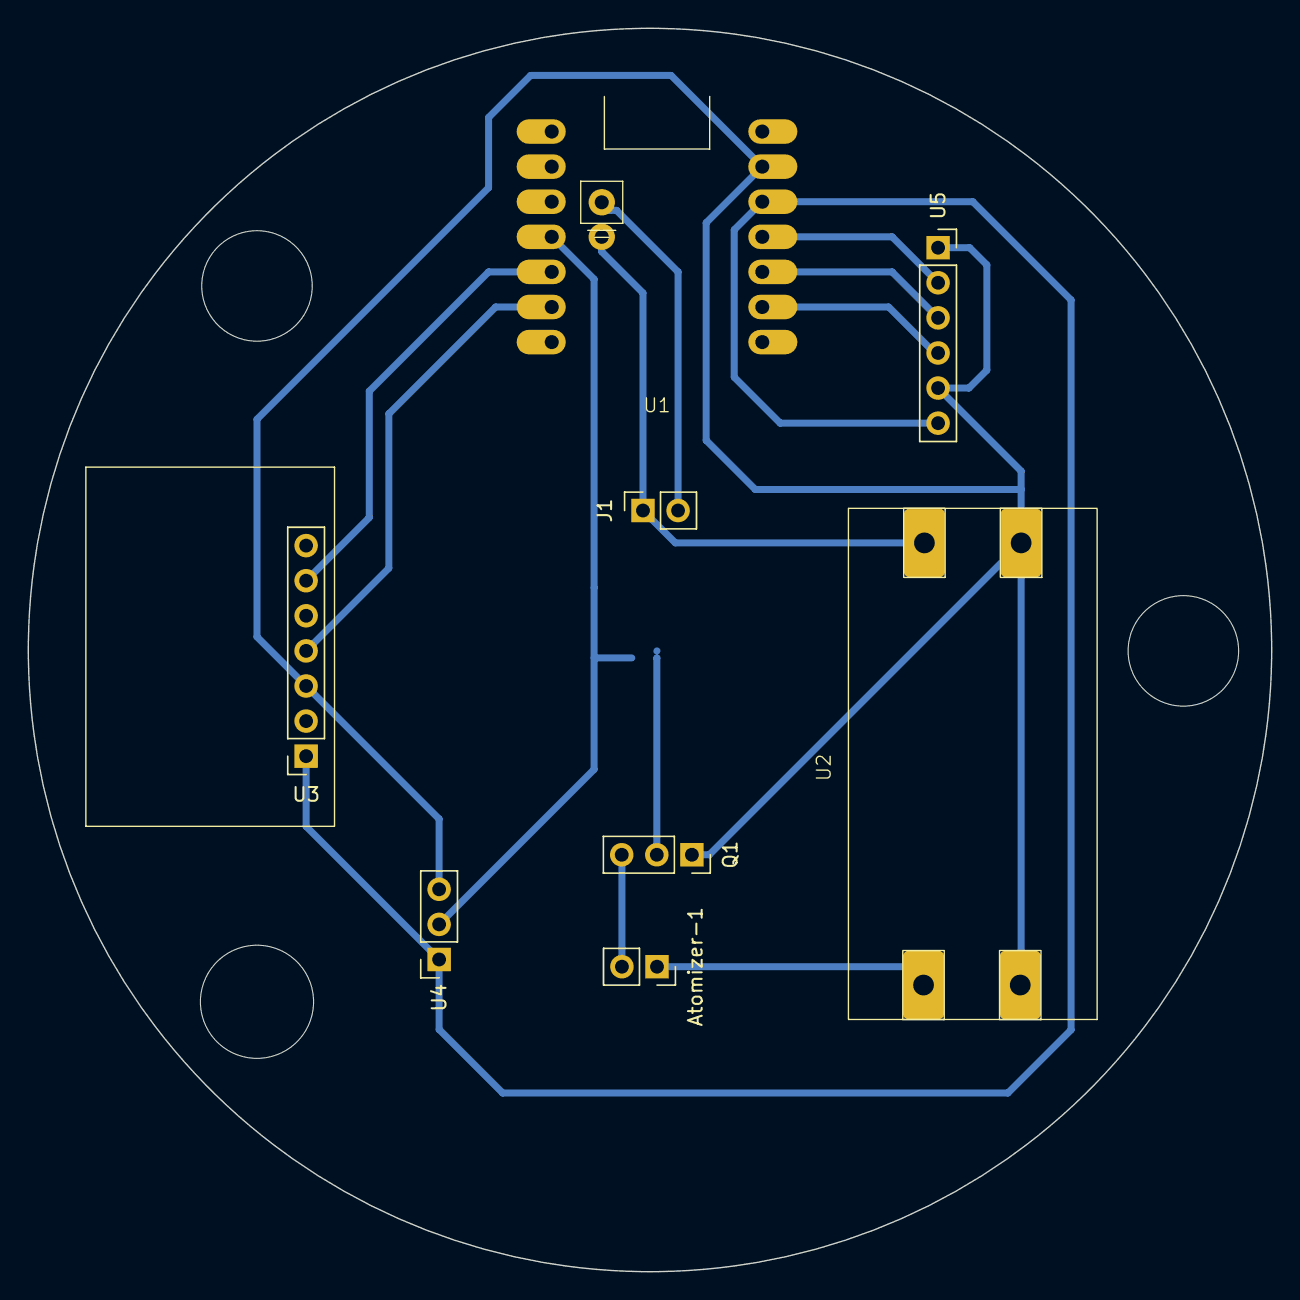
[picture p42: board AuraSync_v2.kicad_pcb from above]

Board: 2 copper layers, 90.0 x 90.0 mm, 9 parts (1 on the bottom side), 13 nets.

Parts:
Atomizer-1: Atomizer; PinSocket_1x02_P2.54mm_Vertical
J1: Battery; PinSocket_1x02_P2.54mm_Vertical
Q1: 2N2222; PinSocket_1x03_P2.54mm_Vertical
R1: 1k; R_0603_1608Metric_Pad0.98x0.95mm_HandSolder
U1: ESP32S3; XIAO_ESP32
U2: MT3608
U3: BME680; PinSocket_1x07_P2.54mm_Vertical
U4: HC-SR501PIR; PinSocket_1x03_P2.54mm_Vertical
U5: SPH0645_Mic; PinSocket_1x06_P2.54mm_Vertical

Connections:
+3.3V: U1.12 (3V3), U3.1 (VIN), U4.1 (VCC), U5.6 (3V)
+5V: Atomizer-1.1, U2.1 (VOUT+)
/BATT+: J1.1, U1.15 (+BATT), U2.3 (VIN+)
/BATT-: J1.2, U1.16 (-BATT)
/BLCK: U1.9 (GPIO7_A8_D8_SCK), U5.4 (BLCK)
/DOUT: U1.11 (GPIO9_A10_D10_MOSI), U5.2 (DOUT)
/LRCL: U1.10 (GPIO8_A9_D9_MISO), U5.3 (LRCL)
/SCL: U1.6 (GPIO6_A5_D5_SCL), U3.4 (SCK)
/SDA: U1.5 (GPIO5_A4_D4_SDA), U3.6 (SDI)
/Signal: R1.2, U1.4 (GPIO4_A3_D3), U4.2 (OUT)
GND: Q1.1 (E), U1.13 (GND), U2.2 (VOUT-), U2.4 (VIN-), U3.3 (GND), U4.3 (GND), U5.1 (SEL), U5.5 (GND)
unnamed: Atomizer-1.2, Q1.3 (C)
unnamed: Q1.2 (B), R1.1

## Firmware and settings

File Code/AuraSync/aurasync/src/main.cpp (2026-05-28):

/*
 * ============================================================
 * AuraSync v4 — Two-layer state machine + on-device ML
 * ============================================================
 * Layer 1 — System mode:  SLEEP ↔ AWAKE  (PIR-driven)
 * Layer 2 — Spray state:  IDLE → SPRAYING → COOLDOWN → IDLE
 *
 * Trigger priority (high → low):
 *   P1  Voice / App     any mode incl. SLEEP; bypass cooldown
 *   P2  IAQ MLP         any mode incl. SLEEP; queues during cooldown
 *                       (consecutive Poor readings; replaces raw gas_ohm threshold)
 *   P3  Shower CNN      any mode incl. SLEEP; fires on shower-end transition
 *   P3  VOC inflection  AWAKE + IDLE only; gas_norm ↓ then ↑ + PIR within 5 s
 *
 * ML models (on-device inference, no cloud):
 *   iaq_model.h    — MLP (64-32), StandardScaler, 3 classes (Good/Moderate/Poor)
 *   shower_model.h — 1D-CNN, threshold 0.65, 30×6 sliding window
 *
 * Build:
 *   Partition Scheme → Custom (partitions.csv)
 *   PSRAM            → OPI PSRAM
 *   Libraries        → Firebase Arduino Client (Mobizt)
 *                      Bosch BSEC2
 *
 * Wiring:
 *   SPH0645 SCK → D8  (GPIO7)   SPH0645 WS  → D9  (GPIO8)
 *   SPH0645 SD  → D10 (GPIO9)   SPH0645 SEL → GND
 *   BME680 SDA  → D4  (GPIO5)   BME680 SCL  → D5  (GPIO6)
 *   PIR OUT     → D1  (GPIO2)   PIR VCC     → 3.3V
 *   Atomizer FET→ D3  (GPIO4)
 * ============================================================
 */

// ── Test / Production mode ────────────────────────────────────
#define TEST_MODE   // comment out for production 3-min CD

#ifdef TEST_MODE
  #define SPRAY_CD_MS        20000UL  // absolute cooldown (shared)
#else
  #define SPRAY_CD_MS       180000UL  // 3 minutes
#endif

// ── Includes ─────────────────────────────────────────────────
#include <Arduino.h>
SET_LOOP_TASK_STACK_SIZE(32 * 1024);
#include <WiFi.h>
#include <time.h>
#include <Wire.h>
#include <Firebase_ESP_Client.h>
#include <bsec2.h>
#include "feature_buffer.h"
#include "iaq_model.h"
#include "shower_model.h"
#include "driver/i2s_std.h"
#include "freertos/FreeRTOS.h"
#include "freertos/task.h"
#include "freertos/queue.h"
#include "esp_heap_caps.h"
#include "esp_afe_sr_iface.h"
#include "esp_afe_sr_models.h"
#include "esp_afe_config.h"
#include "esp_mn_iface.h"
#include "esp_mn_models.h"
#include "model_path.h"
#include "esp_mn_speech_commands.h"
#include "secrets.h"
#include <FastLED.h>

// ── Pins / I2S ───────────────────────────────────────────────
#define I2S_SCK         D8      // GPIO7
#define I2S_WS          D9      // GPIO8
#define I2S_SD          D10     // GPIO9
#define PIN_PIR         2       // GPIO2
#define PIN_ATOMIZER    4       // GPIO4
#define PIN_LED         21
#define PIN_LED_RING    3       // GPIO3 / D2 → WS2812B DI
#define NUM_LEDS        24

#define I2S_SAMPLE_RATE 16000
#define DMA_BUF_COUNT   4
#define DMA_BUF_LEN     256

static i2s_chan_handle_t rx_chan = NULL;

// ── Voice command IDs ─────────────────────────────────────────
#define CMD_ID_AURA   0
#define CMD_ID_SPRAY  1
#define CMD_ID_STOP   2

// ── Demo mode ────────────────────────────────────────────────
// Uncomment for classroom demo: ~30s warmup, faster triggers.
// Comment out for production (9-min warmup, conservative thresholds).
#define DEMO_MODE

// ── Timing ───────────────────────────────────────────────────
#define SPRAY_MS           5000UL   // atomizer on-duration
#define AWAKE_TIMEOUT_MS  60000UL   // no PIR for 60s → SLEEP
#define PIR_HOLD_MS        3000UL   // PIR hold to count as "detected"
#define PIR_GRACE_MS       1500UL
#ifdef DEMO_MODE
  #define BSEC_DECIMATE            1    // push every callback (~3s per reading)
  #define IAQ_MIN_COUNT           10    // start IAQ after 10 readings (~30s)
  #define CNN_MIN_COUNT           10    // start CNN after 10 readings (~30s)
  #define IAQ_POOR_COUNT           2    // 2 × 3s = ~6s of bad air → spray
  #define SHOWER_CONSEC_MIN        2    // 2 × 15s = ~30s shower → spray
  #define P3_PIR_WINDOW_MS    60000UL  // PIR counts as "active" for 60s (demo)
  #define P3_INFLECT_WINDOW_MS 60000UL // inflection latch valid for 60s (demo)
#else
  #define BSEC_DECIMATE            3    // push every 3rd callback (~9s per reading)
  #define IAQ_MIN_COUNT           60    // start IAQ after 60 readings (~9min)
  #define CNN_MIN_COUNT           30    // start CNN after 30 readings (~4.5min)
  #define IAQ_POOR_COUNT           5    // 5 × 9s = ~45s
  #define SHOWER_CONSEC_MIN        6    // 6 × 45s = ~270s
  #define P3_PIR_WINDOW_MS      5000UL  // PIR counts as "active" for 5s
  #define P3_INFLECT_WINDOW_MS 30000UL  // inflection latch valid for 30s
#endif
#define VOICE_WINDOW_MS    7000UL   // Aura → Spray window
#define FB_POLL_MS         3000UL

const unsigned long WIFI_TIMEOUT_MS = 15000;

// ════════════════════════════════════════════════════════════
//  Layer 1 — System mode
// ════════════════════════════════════════════════════════════
enum SysMode { MODE_SLEEP, MODE_AWAKE };
volatile SysMode sysMode = MODE_SLEEP;

static unsigned long lastPirHighMs   = 0;  // last confirmed PIR HIGH
static unsigned long pirFirstMs      = 0;  // PIR hold start

// ════════════════════════════════════════════════════════════
//  Layer 2 — Spray state
// ════════════════════════════════════════════════════════════
enum SprayState { SPRAY_IDLE, SPRAY_SPRAYING, SPRAY_COOLDOWN };
volatile SprayState sprayState  = SPRAY_IDLE;
static unsigned long sprayStateMs = 0;  // millis when state entered
static char activeTrigger[16]   = "none";

// P2 fires during COOLDOWN → spray when CD expires
static bool p2Pending = false;

// ════════════════════════════════════════════════════════════
//  Voice listen window (P1 internal)
// ════════════════════════════════════════════════════════════
static bool          voiceWindow      = false;
static unsigned long voiceWindowStart = 0;

// SR task writes these just before xQueueSend; loop() reads after dequeue
// Single-producer single-consumer, no mutex needed
volatile float lastWordProb    = 0.0f;
volatile char  lastWordStr[16] = {};

// ════════════════════════════════════════════════════════════
//  BME680 / BSEC2
// ════════════════════════════════════════════════════════════
Bsec2 bsec2;
bool  bmeReady  = false;
static int bsecCallCnt = 0;  // decimation counter (push every 3 LP callbacks ≈ 9s)

// ── Ring buffer (defined here, declared extern in feature_buffer.h) ─────────
FBReading fb_ring[BUF_SIZE] = {};
int       fb_head            = 0;
int       fb_count           = 0;

// ── ML inference state ────────────────────────────────────────────────────────
static bool          wasShower       = false;
static int           showerConsec    = 0;
static int           mlSampleCnt     = 0;
static int           iaqPoorCount    = 0;
static unsigned long lastInflectionMs = 0;  // when last VOC inflection was detected
static int           iaqClass        = 0;   // 0=Good, 1=Moderate, 2=Poor (updated by IAQ MLP)

// ── LED ring ──────────────────────────────────────────────────
static CRGB leds[NUM_LEDS];

// ════════════════════════════════════════════════════════════
//  ESP-SR
// ════════════════════════════════════════════════════════════
static const esp_afe_sr_iface_t *afe_handle = NULL;
static esp_afe_sr_data_t        *afe_data   = NULL;
static esp_mn_iface_t           *multinet   = NULL;
static model_iface_data_t       *model_data = NULL;
static QueueHandle_t             cmdQueue   = NULL;
TaskHandle_t                     srTaskHandle = NULL;

// ════════════════════════════════════════════════════════════
//  Firebase
// ════════════════════════════════════════════════════════════
FirebaseData   fbdo;
FirebaseData   fbCmd;
FirebaseAuth   fbAuth;
FirebaseConfig fbConfig;
bool           firebaseReady = false;
static unsigned long lastFbPollMs      = 0;
static unsigned long lastSensorPushMs  = 0;
static unsigned long lastSettingsPollMs = 0;
#define SENSOR_PUSH_MS   5000UL
#define SETTINGS_POLL_MS 10000UL
static bool autoSprayEnabled = true;

// ── Forward declarations ──────────────────────────────────────
void connectWiFi();
void syncNTP();
void initFirebase();
void initI2S();
bool initESPSR();
bool initBME680();
void srProcessingTask(void *pvParam);
void pushSprayEvent(const char *trigger, unsigned long durationMs);
void pushSensorData(float gas_ohm, float temp_c, float hum);
void pollFirebaseSettings();

void enterMode(SysMode m);
void updateMode();
void enterSprayState(SprayState s);
void startSpray(const char *trigger, bool bypassCD);
void stopSpray();
void updateSpray();
void processVoiceCmd(int cmd);
void onBsecData(const bme68xData data, const bsecOutputs outputs, const Bsec2 bsec);
void pollFirebaseCommands();


// ════════════════════════════════════════════════════════════
//  setup()
// ════════════════════════════════════════════════════════════
void setup() {
  Serial.begin(115200);
  delay(5000);  // wait for USB CDC host to reconnect after reset
  Serial.println("=== AuraSync boot ===");

  if (!psramInit()) Serial.println("ERROR:psram_failed");

  pinMode(PIN_LED,      OUTPUT); digitalWrite(PIN_LED,      LOW);
  pinMode(PIN_ATOMIZER, OUTPUT); digitalWrite(PIN_ATOMIZER, LOW);
  pinMode(PIN_PIR,      INPUT);

  Wire.begin(5, 6);  // SDA=GPIO5, SCL=GPIO6
  bmeReady = initBME680();

  connectWiFi();
  if (WiFi.status() == WL_CONNECTED) {
    syncNTP();
    initFirebase();
  }

  cmdQueue = xQueueCreate(8, sizeof(int));

  if (initESPSR()) {
    initI2S();
    BaseType_t ret = xTaskCreatePinnedToCore(
      srProcessingTask, "sr_task",
      12 * 1024, NULL, configMAX_PRIORITIES - 1, &srTaskHandle, 1
    );
    if (ret != pdPASS) Serial.println("ERROR:sr_task_failed");
  } else {
    Serial.println("ERROR:espsr_init_failed");
  }

  FastLED.addLeds<WS2812B, PIN_LED_RING, GRB>(leds, NUM_LEDS);
  FastLED.setBrightness(128);
  fill_solid(leds, NUM_LEDS, CRGB::Black);
  FastLED.show();

  enterMode(MODE_SLEEP);
  enterSprayState(SPRAY_IDLE);
}


// ════════════════════════════════════════════════════════════
//  updateLEDRing() — WS2812B 24-LED breathing / animation
// ════════════════════════════════════════════════════════════
void updateLEDRing() {
  static unsigned long lastLedMs = 0;
  if (millis() - lastLedMs < 16) return;  // ~60fps cap
  lastLedMs = millis();

  unsigned long t = millis();

  // ── Helper: sine breathing → brightness 0..maxBri ───────
  auto breathBri = [](unsigned long t_ms, unsigned long period_ms, uint8_t maxBri) -> uint8_t {
    float phase = (float)(t_ms % period_ms) / period_ms;
    float s = (sinf(phase * 2.0f * (float)M_PI - (float)M_PI / 2.0f) + 1.0f) / 2.0f;
    return (uint8_t)(s * maxBri);
  };

  if (sprayState == SPRAY_SPRAYING) {
    // White rotating chase — 3 bright pixels spinning
    int pos = (t / 30) % NUM_LEDS;
    fill_solid(leds, NUM_LEDS, CRGB::Black);
    for (int i = 0; i < 4; i++) {
      uint8_t bri = 255 - i * 55;
      leds[(pos - i + NUM_LEDS) % NUM_LEDS] = CRGB(bri, bri, bri);
    }

  } else if (sprayState == SPRAY_COOLDOWN) {
    // Cyan fade out over cooldown duration
    float progress = (float)(t - sprayStateMs) / (float)SPRAY_CD_MS;
    progress = constrain(progress, 0.0f, 1.0f);
    uint8_t bri = (uint8_t)((1.0f - progress) * 120);
    fill_solid(leds, NUM_LEDS, CRGB(0, bri, bri));

  } else if (voiceWindow) {
    // Purple quick double-pulse then steady
    unsigned long elapsed = t - voiceWindowStart;
    uint8_t bri = (elapsed < 200 || (elapsed > 300 && elapsed < 500)) ? 200 : 80;
    fill_solid(leds, NUM_LEDS, CRGB(bri / 2, 0, bri));

  } else if (sysMode == MODE_SLEEP) {
    // Very dim slow blue breathing (8s cycle)
    uint8_t bri = breathBri(t, 8000, 18);
    fill_solid(leds, NUM_LEDS, CRGB(0, 0, bri));

  } else {
    // AWAKE — color and speed by IAQ class
    switch (iaqClass) {
      case 0: {  // Good — green slow breathing 4s
        uint8_t bri = breathBri(t, 4000, 80);
        fill_solid(leds, NUM_LEDS, CRGB(0, bri, 0));
        break;
      }
      case 1: {  // Moderate — yellow medium 2s
        uint8_t bri = breathBri(t, 2000, 120);
        fill_solid(leds, NUM_LEDS, CRGB(bri, bri / 2, 0));
        break;
      }
      case 2: {  // Poor — orange fast pulse 0.5s
        uint8_t bri = breathBri(t, 500, 200);
        fill_solid(leds, NUM_LEDS, CRGB(bri, bri / 4, 0));
        break;
      }
    }
  }

  FastLED.show();
}

// ════════════════════════════════════════════════════════════
//  loop()  [Core 0]
// ════════════════════════════════════════════════════════════
void loop() {
  updateMode();   // Layer 1
  updateSpray();  // Layer 2 timers

  int cmd;
  if (xQueueReceive(cmdQueue, &cmd, 0) == pdTRUE) {
    processVoiceCmd(cmd);  // P1
  }

  // Expire voice window without a follow-up command
  if (voiceWindow && millis() - voiceWindowStart >= VOICE_WINDOW_MS) {
    voiceWindow = false;
  }

  if (bmeReady) bsec2.run();  // P2 + P3/P4 via bsecCallback
  pollFirebaseCommands();   // App commands
  pollFirebaseSettings();   // App settings (autoSpray toggle, duration)
  updateLEDRing();

  if (firebaseReady) Firebase.ready();

  // SLEEP mode: throttle Core 0 poll rate to reduce idle CPU burn.
  // 80ms is safe — PIR_HOLD_MS is 3000ms so we won't miss a detection.
  // SR task (Core 1) runs unaffected; voice remains fully responsive.
  if (sysMode == MODE_SLEEP) delay(80);
}


// ════════════════════════════════════════════════════════════
//  Layer 1 — mode transitions
// ════════════════════════════════════════════════════════════
void enterMode(SysMode m) {
  sysMode = m;
  Serial.println(m == MODE_AWAKE ? "MODE:awake" : "MODE:sleep");
}

void updateMode() {
  unsigned long now    = millis();
  bool          pirHigh = digitalRead(PIN_PIR);

  if (pirHigh) {
    lastPirHighMs = now;
    if (pirFirstMs == 0) pirFirstMs = now;
    if (sysMode == MODE_SLEEP) enterMode(MODE_AWAKE);
  } else if (now - lastPirHighMs > PIR_GRACE_MS) {
    pirFirstMs = 0;
  }

  if (sysMode == MODE_AWAKE && now - lastPirHighMs >= AWAKE_TIMEOUT_MS) {
    enterMode(MODE_SLEEP);
  }
}


// ════════════════════════════════════════════════════════════
//  Layer 2 — spray state transitions
// ════════════════════════════════════════════════════════════
void enterSprayState(SprayState s) {
  sprayState   = s;
  sprayStateMs = millis();
  switch (s) {
    case SPRAY_IDLE:     Serial.println("SPRAY:idle");     break;
    case SPRAY_SPRAYING: {
      const char *reason = "unknown";
      if      (strcmp(activeTrigger, "voice")         == 0) reason = "Voice command (Aura->Spray)";
      else if (strcmp(activeTrigger, "app")            == 0) reason = "App command";
      else if (strcmp(activeTrigger, "iaq_poor")       == 0) reason = "Poor air quality (IAQ ML model)";
      else if (strcmp(activeTrigger, "p3_shower_end")  == 0) reason = "Shower detected (CNN model)";
      else if (strcmp(activeTrigger, "p3_inflection")  == 0) reason = "VOC inflection + PIR";
      Serial.printf("SPRAY:spraying  reason=%s\n", reason);
      break;
    }
    case SPRAY_COOLDOWN: Serial.println("SPRAY:cooldown"); break;
  }
}

// bypassCD=true: voice / app (can re-spray during COOLDOWN)
// bypassCD=false: all sensor triggers (blocked by COOLDOWN)
void startSpray(const char *trigger, bool bypassCD) {
  if (sprayState == SPRAY_SPRAYING) return;
  if (sprayState == SPRAY_COOLDOWN && !bypassCD) return;
  strncpy(activeTrigger, trigger, sizeof(activeTrigger) - 1);
  activeTrigger[sizeof(activeTrigger) - 1] = '\0';
  digitalWrite(PIN_ATOMIZER, HIGH);
  digitalWrite(PIN_LED,      HIGH);
  enterSprayState(SPRAY_SPRAYING);
}

void stopSpray() {
  if (sprayState != SPRAY_SPRAYING) return;
  unsigned long actual = millis() - sprayStateMs;
  digitalWrite(PIN_ATOMIZER, LOW);
  digitalWrite(PIN_LED,      LOW);
  enterSprayState(SPRAY_COOLDOWN);
  pushSprayEvent(activeTrigger, actual);
}

void updateSpray() {
  unsigned long elapsed = millis() - sprayStateMs;

  switch (sprayState) {
    case SPRAY_SPRAYING:
      if (elapsed >= SPRAY_MS) {
        digitalWrite(PIN_ATOMIZER, LOW);
        digitalWrite(PIN_LED,      LOW);
        pushSprayEvent(activeTrigger, SPRAY_MS);
        enterSprayState(SPRAY_COOLDOWN);
      }
      break;

    case SPRAY_COOLDOWN:
      if (elapsed >= SPRAY_CD_MS) {
        enterSprayState(SPRAY_IDLE);
        if (p2Pending) {
          p2Pending = false;
          startSpray("iaq_poor", false);
        }
      }
      break;

    default: break;
  }
}


// ════════════════════════════════════════════════════════════
//  P1 — Voice commands  (bypass CD; Spray only in AWAKE)
// ════════════════════════════════════════════════════════════
void processVoiceCmd(int cmd) {
  bool inWindow = voiceWindow && (millis() - voiceWindowStart < VOICE_WINDOW_MS);

  switch (cmd) {

    case CMD_ID_AURA:
      // Aura is the wake word — always print, always open window
      voiceWindow      = true;
      voiceWindowStart = millis();
      Serial.println("VOICE:aura");
      for (int i = 0; i < 2; i++) {
        digitalWrite(PIN_LED, HIGH); delay(150);
        digitalWrite(PIN_LED, LOW);  delay(150);
      }
      break;

    case CMD_ID_SPRAY:
      if (inWindow) {
        // Only print if in window (counts); outside = false positive, ignore silently
        Serial.printf("WORD:%s:%.2f\n", (const char *)lastWordStr, lastWordProb);
        voiceWindow = false;
        startSpray("voice", true);      // bypass CD; works in SLEEP and AWAKE
        if (sysMode == MODE_SLEEP) {    // wake system when voice triggers spray
          enterMode(MODE_AWAKE);
          lastPirHighMs = millis();
        }
      }
      break;

    case CMD_ID_STOP:
      if (inWindow || sprayState == SPRAY_SPRAYING) {
        // Print if in window, or if actively stopping a spray (always meaningful)
        Serial.printf("WORD:%s:%.2f\n", (const char *)lastWordStr, lastWordProb);
        voiceWindow = false;
        if (sprayState == SPRAY_SPRAYING) stopSpray();
      }
      break;
  }
}


// ════════════════════════════════════════════════════════════
//  BSEC2 callback — sensor data + ML inference
//  Fires at ~3s (BSEC_SAMPLE_RATE_LP); decimated 3x to ~9s for ML.
// ════════════════════════════════════════════════════════════
void onBsecData(const bme68xData data, const bsecOutputs outputs, const Bsec2 bsec) {
  float gas_ohm = 0.0f, temp_c = 0.0f, hum = 0.0f;
  for (uint8_t i = 0; i < outputs.nOutputs; i++) {
    switch (outputs.output[i].sensor_id) {
      case BSEC_OUTPUT_RAW_GAS:
        gas_ohm = outputs.output[i].signal; break;
      case BSEC_OUTPUT_RAW_TEMPERATURE:
        temp_c  = outputs.output[i].signal; break;
      case BSEC_OUTPUT_RAW_HUMIDITY:
        hum     = outputs.output[i].signal; break;
    }
  }

  // ── Decimate: push every BSEC_DECIMATE callbacks ────────────
  if (++bsecCallCnt % BSEC_DECIMATE != 0 || gas_ohm <= 0.0f) return;
  Serial.printf("[BME] gas=%.0f t=%.1f h=%.1f cnt=%d\n", gas_ohm, temp_c, hum, fb_count);
  fb_push(gas_ohm, temp_c, hum);
  pushSensorData(gas_ohm, temp_c, hum);

  // ── IAQ: MLP classifier (any mode; wakes system; queues during cooldown) ──
  // Replaces raw gas_ohm threshold — model uses gas_norm + humidity + temp features.
  if (fb_count >= IAQ_MIN_COUNT) {
    float feat[10]; computeIAQFeatures(feat);
    int cls = predictIAQ(feat);  // 0=Good, 1=Moderate, 2=Poor
    iaqClass = cls;
    Serial.printf("[IAQ] cls=%d gn=%.3f hum=%.1f gas=%.0f\n",
                  cls, fb_get_gas_norm(0), fb_get_hum(0), fb_at(0)->gas_ohm);
    if (cls == 2) {
      if (++iaqPoorCount >= IAQ_POOR_COUNT) {
        iaqPoorCount = 0;
        if (autoSprayEnabled) {
          if (sprayState == SPRAY_COOLDOWN) {
            p2Pending = true;
          } else if (sprayState == SPRAY_IDLE) {
            if (sysMode == MODE_SLEEP) { enterMode(MODE_AWAKE); lastPirHighMs = millis(); }
            startSpray("iaq_poor", false);
          }
        }
      }
    } else {
      iaqPoorCount = 0;
    }
  }

  // ── P3: VOC inflection + PIR (AWAKE + IDLE only) ────────────────
  if (fb_count >= 3) {
    float g0 = fb_get_gas_norm(0), g1 = fb_get_gas_norm(1), g2 = fb_get_gas_norm(2);
    bool wasDeclining = (g1 < g2);
    bool nowRising    = (g0 > g1);
    if (wasDeclining && nowRising) {
      lastInflectionMs = millis();
      Serial.printf("[P3] VOC inflection latched  gn=%.3f→%.3f→%.3f\n", g2, g1, g0);
    }

    bool inflectionRecent = (lastInflectionMs > 0 &&
                             millis() - lastInflectionMs < P3_INFLECT_WINDOW_MS);
    bool pirRecent        = (millis() - lastPirHighMs   < P3_PIR_WINDOW_MS);
    if (autoSprayEnabled && sysMode == MODE_AWAKE && sprayState == SPRAY_IDLE &&
        inflectionRecent && pirRecent) {
      lastInflectionMs = 0;
      startSpray("p3_inflection", false);
    }
  }

  // ── P3: Shower CNN (any mode; triggers on shower-end transition) ─
  if (fb_count >= CNN_MIN_COUNT && (++mlSampleCnt % 5 == 0)) {
    static float win[30][6]; computeShowerWindow(win);
    float prob = predictShower(win);
    bool isShower = (prob >= CNN_THRESHOLD);
    Serial.printf("[CNN] shower_prob=%.2f\n", prob);
    if (autoSprayEnabled && wasShower && !isShower && showerConsec >= SHOWER_CONSEC_MIN)
      startSpray("p3_shower_end", true);
    showerConsec = isShower ? showerConsec + 1 : 0;
    wasShower    = isShower;
  }
}
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

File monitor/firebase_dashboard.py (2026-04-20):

"""
AuraSync Firebase Dashboard — real-time spray event monitor
Run: streamlit run firebase_dashboard.py
"""

import os
import time
from datetime import datetime
from zoneinfo import ZoneInfo

import requests
import pandas as pd
import plotly.graph_objects as go
import streamlit as st

# Load .env if present (development); in production set env vars directly
try:
    from dotenv import load_dotenv
    load_dotenv()
except ImportError:
    pass

# ── Config ────────────────────────────────────────────────────────────────────
DATABASE_URL    = os.getenv("DATABASE_URL", "")
DATABASE_SECRET = os.getenv("DATABASE_SECRET", "")
REFRESH_S       = 5
TZ              = ZoneInfo("America/Los_Angeles")
TZ_LABEL        = "Seattle"

st.set_page_config(page_title="AuraSync Monitor", page_icon="💧", layout="wide")

# ── Theme state ───────────────────────────────────────────────────────────────
if "dark" not in st.session_state:
    st.session_state.dark = True

dark = st.session_state.dark

# ── CSS ───────────────────────────────────────────────────────────────────────
if dark:
    VARS = """
      --bg:        #09090b;
      --surface:   #111113;
      --surface-2: #1c1c1f;
      --border:    #2e2e32;
      --text:      #fafafa;
      --text-2:    #8c8c99;
      --text-3:    #4a4a55;
      --accent:    #22d3ee;
      --accent-bg: rgba(34,211,238,.07);
      --green:     #4ade80;
      --green-bg:  rgba(74,222,128,.08);
      --shadow:    0 0 0 1px #2e2e32, 0 8px 32px rgba(0,0,0,.5);
    """
    pg   = "#09090b"
    grid = "#1c1c1f"
    txc  = "#8c8c99"
    acc  = "#22d3ee"
else:
    VARS = """
      --bg:        #f1f5f9;
      --surface:   #ffffff;
      --surface-2: #f8fafc;
      --border:    #e2e8f0;
      --text:      #0f172a;
      --text-2:    #64748b;
      --text-3:    #94a3b8;
      --accent:    #0891b2;
      --accent-bg: rgba(8,145,178,.06);
      --green:     #16a34a;
      --green-bg:  rgba(22,163,74,.07);
      --shadow:    0 0 0 1px #e2e8f0, 0 4px 16px rgba(0,0,0,.06);
    """
    pg   = "#f1f5f9"
    grid = "#f1f5f9"
    txc  = "#94a3b8"
    acc  = "#0891b2"

st.markdown(f"""
<style>
:root {{ {VARS} }}

/* ── Streamlit reset ── */
.stApp, section.main, .stApp > div {{
    background: var(--bg) !important;
}}
.block-container {{
    padding: 28px 36px 60px !important;
    max-width: 1440px !important;
}}
#MainMenu, footer, header,
[data-testid="stToolbar"],
[data-testid="stDecoration"] {{ display: none !important; }}

/* ── Typography ── */
*, p, div, span, h1, h2, h3 {{ color: var(--text); }}

/* ── Metric card ── */
.mc {{
    background: var(--surface);
    box-shadow: var(--shadow);
    border-radius: 16px;
    padding: 22px 24px 18px;
    height: 100%;
}}
.mc-label {{
    font-size: 10px; font-weight: 700;
    letter-spacing: .16em; text-transform: uppercase;
    color: var(--text-3); margin-bottom: 12px;
}}
.mc-value {{
    font-size: 42px; font-weight: 800;
    line-height: 1; letter-spacing: -.02em;
    color: var(--text);
    font-variant-numeric: tabular-nums;
}}
.mc-value.hi {{ color: var(--accent); }}
.mc-sub {{
    font-size: 12px; color: var(--text-2);
    margin-top: 6px;
    font-variant-numeric: tabular-nums;
}}

/* ── Section label ── */
.sl {{
    font-size: 10px; font-weight: 700;
    letter-spacing: .16em; text-transform: uppercase;
    color: var(--text-3); margin: 32px 0 14px;
}}

/* ── Chart card ── */
.cc {{
    background: var(--surface);
    box-shadow: var(--shadow);
    border-radius: 16px;
    padding: 20px 16px 12px;
}}
.cc-title {{
    font-size: 10px; font-weight: 700;
    letter-spacing: .14em; text-transform: uppercase;
    color: var(--text-3); padding-left: 4px; margin-bottom: 4px;
}}

/* ── Event row ── */
.er {{
    display: flex; align-items: center; gap: 16px;
    padding: 13px 18px;
    background: var(--surface);
    box-shadow: var(--shadow);
    border-radius: 12px;
    margin-bottom: 8px;
    transition: box-shadow .15s;
}}
.er-bar {{
    width: 3px; height: 28px; border-radius: 2px;
    background: var(--accent); flex-shrink: 0;
}}
.er-cmd {{
    font-size: 11px; font-weight: 800;
    letter-spacing: .12em; text-transform: uppercase;
    color: var(--accent); min-width: 48px;
}}
.er-time {{
    font-size: 13.5px; color: var(--text);
    font-variant-numeric: tabular-nums; flex: 1;
}}
.er-ago {{
    font-size: 12px; color: var(--text-3);
    background: var(--surface-2);
    padding: 3px 8px; border-radius: 6px;
}}

/* ── Live pill ── */
.lp {{
    display: inline-flex; align-items: center; gap: 6px;
    background: var(--green-bg);
    border: 1px solid var(--green);
    border-radius: 999px; padding: 5px 12px;
    font-size: 10px; font-weight: 800;
    letter-spacing: .14em; color: var(--green);
}}
.ld {{
    width: 6px; height: 6px; border-radius: 50%;
    background: var(--green);
    animation: blink 1.5s ease-in-out infinite;
}}
@keyframes blink {{
    0%,100%{{ opacity:1; }} 50%{{ opacity:.2; }}
}}
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

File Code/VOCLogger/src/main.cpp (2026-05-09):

/*
 * VOCLogger — BME680 + BSEC2 IAQ data collection
 *
 * Uses Bosch BSEC2 library (ESP32-S3 compatible) for calibrated IAQ output.
 * BSEC2 uses a callback model: outputs are captured in onBsecData() and
 * stored in the `latest` struct; Firebase push reads from there.
 *
 * Board  : Seeed XIAO ESP32-S3 (native USB CDC)
 */

#include <WiFi.h>
#include <Wire.h>
#include <time.h>
#include <Preferences.h>
#include <Firebase_ESP_Client.h>
#include "addons/TokenHelper.h"
#include "bsec2.h"
#include "secrets.h"

// ── Pins ──────────────────────────────────────────────────────────────────────
#define PIN_SDA  5
#define PIN_SCL  6
#define PIN_LED  21

// ── Timing ────────────────────────────────────────────────────────────────────
#define PUSH_INTERVAL_MS   10000UL
#define STATE_SAVE_PERIOD  200
#define WIFI_TIMEOUT_MS    20000UL

// ── Firebase ──────────────────────────────────────────────────────────────────
FirebaseData   fbdo;
FirebaseAuth   fbAuth;
FirebaseConfig fbConfig;
bool           fbReady     = false;
int            fbFailCount = 0;
const int      FB_FAIL_LIMIT = 5;

// ── BSEC2 ─────────────────────────────────────────────────────────────────────
Bsec2       iaqSensor;
Preferences prefs;
uint32_t    bsecCycleCount = 0;
bool        newBsecData    = false;
int         dbgBeginRet    = -1;
int         dbgStatus      = -1;

struct {
    float   temperature   = 0;
    float   humidity      = 0;
    float   pressure      = 0;
    float   gasResistance = 0;
    float   iaq           = 0;
    uint8_t iaqAccuracy   = 0;
    float   staticIaq     = 0;
    float   co2Equivalent = 0;
    float   breathVoc     = 0;
    bool    heaterStable  = false;
} latest;

// ── Session state ─────────────────────────────────────────────────────────────
char sessionId[32];
char sessionPath[64];
unsigned long bootMs = 0;

// ── Push timing ───────────────────────────────────────────────────────────────
unsigned long lastPushMs = 0;
bool          firstPush  = true;

// ── LED ───────────────────────────────────────────────────────────────────────
unsigned long lastLedMs  = 0;
bool          ledState   = false;
bool          errorState = false;

// ─────────────────────────────────────────────────────────────────────────────

void setError(bool err) { errorState = err; }

void blinkLED() {
  unsigned long interval = errorState ? 100UL : 500UL;
  if (millis() - lastLedMs < interval) return;
  lastLedMs = millis();
  ledState  = !ledState;
  digitalWrite(PIN_LED, ledState ? HIGH : LOW);
}

// ── BSEC2 callback ────────────────────────────────────────────────────────────
void onBsecData(const bme68xData data, const bsecOutputs outputs, const Bsec2 bsec) {
  if (!outputs.nOutputs) return;
  for (uint8_t i = 0; i < outputs.nOutputs; i++) {
    const bsecData& o = outputs.output[i];
    switch (o.sensor_id) {
      case BSEC_OUTPUT_SENSOR_HEAT_COMPENSATED_TEMPERATURE:
        latest.temperature   = o.signal; break;
      case BSEC_OUTPUT_SENSOR_HEAT_COMPENSATED_HUMIDITY:
        latest.humidity      = o.signal; break;
      case BSEC_OUTPUT_RAW_PRESSURE:
        latest.pressure      = o.signal; break;
      case BSEC_OUTPUT_RAW_GAS:
        latest.gasResistance = o.signal; break;
      case BSEC_OUTPUT_IAQ:
        latest.iaq           = o.signal;
        latest.iaqAccuracy   = o.accuracy; break;
      case BSEC_OUTPUT_STATIC_IAQ:
        latest.staticIaq     = o.signal; break;
      case BSEC_OUTPUT_CO2_EQUIVALENT:
        latest.co2Equivalent = o.signal; break;
      case BSEC_OUTPUT_BREATH_VOC_EQUIVALENT:
        latest.breathVoc     = o.signal; break;
      case BSEC_OUTPUT_STABILIZATION_STATUS:
        latest.heaterStable  = (o.signal == 1.0f); break;
      default: break;
    }
  }
  newBsecData = true;
  bsecCycleCount++;
}

// ── Wi-Fi ─────────────────────────────────────────────────────────────────────
void connectWiFi() {
  for (int attempt = 1; attempt <= 3; attempt++) {
    Serial.printf("Connecting to \"%s\" (attempt %d)", WIFI_SSID, attempt);
    WiFi.disconnect(true);
    WiFi.mode(WIFI_STA);
    WiFi.setSleep(WIFI_PS_MAX_MODEM);
    WiFi.begin(WIFI_SSID, WIFI_PASSWORD);
    unsigned long t = millis();
    while (WiFi.status() != WL_CONNECTED) {
      if (millis() - t > WIFI_TIMEOUT_MS) break;
      delay(500);
      Serial.print(".");
    }
    if (WiFi.status() == WL_CONNECTED) {
      Serial.printf("\nWiFi OK  IP=%s\n", WiFi.localIP().toString().c_str());
      delay(2000);
      return;
    }
    Serial.println("\nTimeout, retrying...");
  }
  Serial.println("ERROR: WiFi failed");
  setError(true);
}

// ── NTP ───────────────────────────────────────────────────────────────────────
void syncNTP() {
  for (int attempt = 1; attempt <= 3; attempt++) {
    configTime(0, 0, "pool.ntp.org", "time.nist.gov");
    Serial.printf("NTP sync (attempt %d)", attempt);
    unsigned long t = millis();
    while (time(nullptr) < 1000000000UL) {
      if (millis() - t > 15000UL) break;
      delay(500);
      Serial.print(".");
    }
    if (time(nullptr) >= 1000000000UL) { Serial.println(" OK"); return; }
    Serial.println(" TIMEOUT");
  }
  Serial.println("ERROR: NTP failed — session ID will be wrong");
}

// ── Session ID ────────────────────────────────────────────────────────────────
void buildSessionId() {
  time_t now = time(nullptr);
  strftime(sessionId, sizeof(sessionId), "%Y%m%d-%H%M%S", gmtime(&now));
  snprintf(sessionPath, sizeof(sessionPath), "/voc_dataset/sessions/%s", sessionId);
  Serial.printf("Session: %s\n", sessionId);
}
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

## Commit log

2026-04-07 feat(web-devlog): KaTeX math, UX polish, week-01 content, GitHub repo URL
    - Add remark-math and rehype-katex with single-dollar math disabled so BOM
    prices stay literal; use \\(...\\) for inline and ... for display math.
    - Import KaTeX CSS; tune markdown-doc styles for dark mode.
    - Fix week-01 gradients and arrows; embed medium-fidelity user flow diagram.
    - Point devlog githubRepo to TECHIN-515-Team6.
    Made-with: Cursor
2026-04-07 feat(web-devlog): AuraSync devlog UI, week-01 content, carryover tasks, user flow diagram
    - Homepage hero, vision, timeline, team copy and motion polish
    - Week 1 markdown: structure, planned_next, HTML user flow diagram embed
    - Prior-week checklist on timeline and week pages via prior_week_progress
    - GitHub repo URL, TOC bookends (Opening / Main / Closing)
    - lucide icons, cursor aura, route transitions, rehype-raw for embeds
    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
2026-04-14 feat(devlog): week-02 content, 7 UX improvements, team & copy updates
    Week content:
    - Add week-02.md: schematic review, firmware skeleton, CAD prototype, ML dataset strategy
    - Add schematic_v1.png to public/images/devlog
    UI/UX improvements:
    - TOC scroll-spy via IntersectionObserver (DevlogToc)
    - Code syntax highlighting with rehype-highlight + dark-mode overrides
    - Image lightbox (ImageLightbox.jsx) with Framer Motion
    - Prev/Next week navigation at bottom of each entry
    - Mobile TOC slide-up drawer + floating trigger button
    - Reading progress bar (ReadingProgress.jsx)
    - Timeline filter tabs (All / In Progress / Completed) with AnimatePresence
    Content & copy fixes:
    - week-01.md: remove numbe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
2026-04-14 fix(devlog): correct Q2 sensor data-rate explanations in week-02
    - BME680: replace misleading heater-cycle sentence with accurate explanation
    (on-chip micro-heater, ~16 mW, auto-managed by Bosch driver, no thermal
    risk; VOC useful for shower detection; note self-heating offset on temp)
    - INMP441: remove erroneous 480,000-sample raw PCM buffer claim; clarify
    DMA frame-based processing (~32 ms frames, raw audio discarded per frame);
    separate voice-command mode (64 KB / 1 s window) from environment mode
    (30 s FFT feature accumulation, no large PCM buffer)
    - Simplify closing blockquote
2026-04-20 Week 3 devlog: voice recognition, PIR sensor, Firebase integration
    - Add week-03.md: SPH0645/ESP-SR voice pipeline, PIR actuation, schematic
    update, and Firebase Realtime Database event logging
    - Fix week-02.md anchor positions for carryover link scrolling
    - Add MentorCard (Justin Ho / T-Mobile), SpecialThanksCard,
    WakeWordStateMachineDiagram, PIRActuationDiagram, StateMachineDiagram
    - Fix ImageLightbox to use createPortal (escapes transform stacking context)
    - Team.jsx: add Week 3 contributions for Yutong and Lucia
    - T-Mobile logo: replace broken URL with local asset (tmo-logo-v4.svg)
    - DevlogWeekPage: conditional next-steps panel via show_next_steps flag
    - devlogDocUtils: dynamic notes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
2026-04-20 feat(week-03): narrative rewrite, Firebase+dashboard, Code/KiCAD/monitor added
    - week-03.md: 5-section rewrite (hardware+voice+serial merged, Firebase+dashboard,
    PIR, schematic, budget); corrected SPH0645 reason, auth story, Lucia/Yutong tags
    - monitor/voice_monitor.py: renamed from app.py
    - monitor/firebase_dashboard.py: new cloud dashboard (dark/light mode, Seattle tz)
    - Code/: AuraSync, VoiceTest, FirebaseTest, MicTest, PsramTest sketches added
    - KiCAD/: schematic + PCB layout added
    - README.md: updated layout, monitor run instructions, FirebaseTest section
    [AuraSync_v1.kicad_pcb, AuraSync_v1.kicad_sch, partitions.csv]
2026-04-20 security: move credentials to secrets.h/.env; update week-02/03 devlog
    Security:
    - FirebaseTest.ino: replace hardcoded SSID/password/secret with #include "secrets.h"
    - firebase_dashboard.py: load DATABASE_URL/SECRET from os.getenv() via python-dotenv
    - Add secrets.h.example and .env.example as templates
    - .gitignore: exclude Code/**/secrets.h and monitor/.env
    - requirements.txt: add requests, pandas, python-dotenv
    Devlog:
    - week-02 Next Steps: mark WiFi & Firebase as ✅ (completed in week 3)
    - week-03: prior_week_progress wifi-firebase → true
    - week-03: replace planned_next with Week 4 plan (PIR+Firebase end-to-end,
    unified state machine, mobile app framework, BME680 bring-up)
    - week-0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
    [FirebaseTest.ino, firebase_dashboard.py]
2026-04-20 feat(week-03): full devlog polish, schematic v2.0, new media assets
    - week-03: enrich body with transition text, result callouts, challenge
    table, section separators; add Firebase Console + cloud dashboard +
    voice monitor screenshots; add voice_monitor_test.mp4 demo video
    - week-03: schematic v2.0 — SPH0645, HC-SR501 PIR, battery connector J2
    - week-03: fix Notes · Mentor Meeting card (regex notes?/mentor in splitter)
    - week-03: update summary to cover schematic update + Milestone Slides
    - week-01/02: executive summary restructured with bullets; week-02 status
    fixed to "Completed" for consistent timeline badge colour
    - devlogDocUtils: broaden notes-panel regex to match notes? and me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
    [AuraSync_v2.kicad_pcb, AuraSync_v2.kicad_sch]
2026-04-20 feat: add Chinese (zh) language support across entire devlog site
    - Add LocaleContext (React context + localStorage persistence) and strings.js
    with full EN/ZH translations covering nav, hero, vision, timeline, team,
    week panels, carryover checklist, credits, and footer
    - Add language toggle button in Nav (中文 ↔ EN)
    - Update all UI components to use locale-aware strings: Hero, Vision, Team,
    DevlogTimeline, DevlogWeekPage, DevlogCredits, DevlogCarryoverChecklist
    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
2026-04-20 content: add enclosure photos (week 2) and PIR test video (week 3)
    Add enclosure_1.png and enclosure_2.png after the early prototype
    description in week-02. Replace placeholder comment with pir_test.mp4
    in week-03 challenges section. Both EN and ZH versions updated.
2026-04-25 feat(week-04): add devlog entry with diagrams, images, and Chinese version
    - Add week-04.md and week-04.zh.md covering BME680 bring-up, AuraSync
    unified firmware, power saving analysis, and two-layer state machine design
    - Add three interactive diagram components: AuraSyncFourStateDiagram,
    TwoLayerStateMachineDiagram, TriggerPriorityDiagram (priority card layout)
    - Wire new diagram embeds into DevlogMarkdownBody.jsx
    - Add BME_log.png and firebase_log.png to public/images/devlog
    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
2026-04-25 docs: add hardware photo, update README, add image to week-04 devlog
    - Add firebase_pir_voice_atomizer.png showing integrated PIR + mic +
    atomizer test setup to public/images/devlog and week-04 devlog (en + zh)
    - Update README: remove BME680 "in transit", add hardware photo, add
    AuraSync flashing instructions, update firmware overview to reflect
    v3 two-layer state machine and power saving numbers, add AtomizerTest
    to repo layout
2026-04-25 feat(code): add AuraSync v3 firmware, partitions, voice monitor HTML
    - AuraSync.ino: two-layer state machine (SLEEP/AWAKE x IDLE/SPRAYING/
    COOLDOWN), four-priority trigger model (P1 voice/app, P2 extreme VOC,
    P3 PIR+VOC inflection), WiFi modem sleep + Core 0 throttle power saving,
    Firebase reverse control polling, Aura-gated serial output
    - partitions.csv: custom flash layout (app0 3.7 MB + model SPIFFS 4.25 MB)
    - secrets.h.example: placeholder template (real secrets.h in .gitignore)
    - voice_monitor.html: Web Serial browser monitor for INMP441 voice pipeline
    - README: update repo layout with new files, add secrets.h setup step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
    [partitions.csv]
2026-04-26 feat(code): add BME680 sensor test project for Seeed XIAO ESP32S3
    PlatformIO project reading temperature, humidity, and VOC gas resistance
    from BME680 via I2C (0x77) using Adafruit BME680 library.
2026-04-28 feat(week-04): add mobile app (Expo SDK 54 + Firebase) and devlog section 4
    - Add mobile-app/ (React Native, Expo SDK 54, Firebase JS SDK 10)
    - App.js: real-time spray history viewer, onValue listener, newest-first
    - firebase.js.example: placeholder config (firebase.js gitignored)
    - package.json / app.json: Expo SDK 54, React 19, RN 0.81.5
    - Update .gitignore: exclude mobile-app/node_modules and mobile-app/firebase.js
    - week-04.md / zh: add section 4 (scope note, tech choice, screenshots embed)
    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
2026-04-29 feat(voc-logger): add VOCLogger sketch for bathroom BME680 data collection
    - Code/VOCLogger/VOCLogger.ino: standalone data-logger (no voice/PIR/atomizer)
    - UW MPSK WiFi, NTP time sync, auto session ID from boot timestamp
    - Samples BME680 every 10 s; pushes temp/humidity/pressure/gas_ohm to Firebase
    - heater_stable=false for first 120 s (cold-start filter for ML pipeline)
    - LED heartbeat: 1 Hz OK, 5 Hz error
    - Firebase path: /voc_dataset/sessions/<YYYYMMDD-HHmmSS>/readings/<push_id>
    - Code/VOCLogger/secrets.h.example: MPSK + Firebase credential placeholders
    [VOCLogger.ino]
2026-05-03 feat(firmware): upgrade BME680 driver to Bosch BSEC2 for self-calibrating IAQ
    Replace Adafruit BME680 library with Bosch-BSEC2-Library (ESP32-S3 compatible).
    BSEC2 provides a calibrated IAQ index (0-500) with self-managing short-term and
    long-term baseline models, solving the multi-day gas_ohm drift problem observed
    after strong VOC exposure.
    Key changes:
    - platformio.ini: switch to Bosch-BSEC2-Library + Bosch-BME68x-Library deps;
    set build_dir to ASCII path to fix Windows linker crash on non-ASCII usernames
    - main.cpp: full rewrite using Bsec2 callback API; BSEC calibration state
    persisted to NVS (survives reboots); multi-WiFi support (UW MPSK + home);
    Serial.setTxTimeoutMs(0) for he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
    [main.cpp]
2026-05-03 feat(ml): add complete ML pipeline scripts and update notebook for BSEC2
    Add four ML pipeline scripts under Code/ml/:
    - fetch_firebase.py: export all Firebase sessions to CSV with heater warmup filter
    - preprocess.py: sliding baseline normalization, IAQ rule labeling, window extraction
    - train_iaq.py: Random Forest IAQ classifier (Good/Moderate/Poor) with GroupKFold CV
    - train_shower.py: 1D-CNN shower event detector with threshold tuning and AUC metrics
    Update AuraSync_ML_Progress.ipynb:
    - Fix timezone handling (tz_convert instead of pd.Timestamp with tz arg)
    - Fix PyTorch weights_only error by saving checkpoint with native Python types
    - Correct IAQ cross-validation F1: 0.90 -> 0.77 (actua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
2026-05-03 data: add raw sessions, processed features, model checkpoints, and plots
    Add Data/ directory with all pipeline artifacts from week 5 dry-run:
    - Data/raw/: 14 Firebase session CSVs + merged all_sessions.csv
    - Data/processed/: feature-engineered CSVs, train/val/test numpy arrays,
    scalers.pkl, and gas_norm diagnostic plots per session
    - Data/models/: IAQ Random Forest (iaq_rf_v1.pkl), Shower 1D-CNN
    (shower_cnn_v1.pt), confusion matrix, feature importance plot, results.json
    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
    [19200530-065424.csv, 19700101-000012.csv, 19700101-000015.csv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]
2026-05-04 devlog: week-05 ML detail, zh translations, team cards weeks 4-5
    - week-05.md: expanded ML section with 6 figures (gas_norm baseline,
    IAQ 5-fold CV bars, confusion matrix, feature importance, CNN arch
    diagram, shower per-class report); corrected dataset stats (10 sessions
    / 16 927 readings, 8 features incl. hour_sin/cos); removed Lucia Devlog
    tag
    - week-05.zh.md: full Chinese translation of enriched week-05
    - week-04.md / week-04.zh.md: check BME680 firmware + VOC baseline as done
    - strings.js: add weeks 4-5 activity items for both team members (EN + ZH);
    update role and bio strings
    - public/images/devlog: add 6 ML PNGs (generated from notebook data)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
2026-05-04 app: redesign UI (Apple smart home), add Firebase spray control
    - App.js: full rewrite — dark iOS-style design, large circular gradient
    spray button, animated status dot, grouped activity list, relative
    timestamps, haptic feedback on spray tap
    - Spray control: writes {action,source,requestedAt} to /commands/action;
    watches node for ESP32 clearance (pending→done→idle); 10 s timeout
    shows error state if device doesn't respond
    - expo-linear-gradient ~15.0.8 + expo-haptics ~15.0.8 added
    - week-05 devlog: Mentor Meeting filled (Justin's 5 points + component
    links); Data Collection section adds 3 deployment photos (waterproofing,
    GIX bathroom, home bathroom) with narrative text;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
    [App.js]
2026-05-04 Week 5 devlog: Firebase reverse control section + app UI screenshots
    - Add Section 4 to week-05.md/.zh.md: bi-directional Firebase protocol,
    sensor/status feedback paths, and full app redesign (EN + ZH)
    - Check firebase-reverse checkbox in week-05 and week-04 Next Steps (EN + ZH)
    - Update week-05 title, summary, and Yutong credits tags
    - Add app-ui-1.png and app-ui-2.png screenshots with captions
    - Rewrite mobile-app/App.js: live sensor card, cooldown bar, auto-spray
    toggle, duration stepper, usage card, reservoir estimate, push notifications,
    light/dark theme via ThemeCtx + makeStyles(C)
    - Add expo-notifications ~0.32.17 to mobile-app/package.json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
    [App.js]
2026-05-04 devlog: week-05 Section 4, app redesign, layout fixes, week-04 completed
    - Add Section 4 (Firebase reverse control + app redesign) to week-05 EN + ZH
    - Add app-ui-screenshots-embed component to DevlogMarkdownBody
    - Check firebase-reverse in week-04 and week-05 carryover checklists (EN + ZH)
    - Update week-05 Next Steps: remove firebase-reverse, merge shower tasks, add enclosure + PCB items
    - Revert DevlogWeekPage checklist/credits to stacked layout; checklist full-width
    - Mark week-04 status as Completed (EN + ZH)
2026-05-09 firmware: fix heater_stable, WiFi, Firebase reliability for home deployment
    - Map heater_stable to STABILIZATION_STATUS (not RUN_IN_STATUS) so it
    becomes true after ~15 min instead of requiring full multi-day run-in;
    fixes fetch_firebase.py filtering out all readings
    - Remove UW MPSK fallback WiFi — home-only deployment, simplifies boot
    - Add Firebase socketConnection/serverResponse timeouts (10 s each)
    - Switch pushJSON → setJSON with unix timestamp key to avoid server-side
    key generation latency
    - Add Firebase.reset()+begin() on push failure for faster SSL recovery
    [main.cpp]
2026-05-09 docs: update CLAUDE.md with current status and firmware fixes for Windows handoff
2026-05-10 feat: ML Round2 data + firmware fixes for demo
    Firmware (AuraSync.ino + feature_buffer.h):
    - Cap gas_ohm at 100k in ring buffer to prevent BSEC2 warmup spikes
    from inflating rolling-max baseline (root cause of P4 false triggers)
    - P4 IAQ trigger: raise consecutive-Poor threshold 3→5, add gas_ohm
    to [IAQ] debug log
    - Voice det threshold 0.0→0.6 to stop ambient false triggers
    - Stack size SET_LOOP_TASK_STACK_SIZE(32KB) for CNN inference
    - BSEC2 I2C addr 0x76→0x77, allow positive status warnings
    ML Round 2 (May 3–9 data, ~110+ sessions):
    - fetch_firebase.py / preprocess.py / train_iaq.py updated
    - IAQ MLP: CV Macro F1 0.989 ± 0.012, Test F1 0.988
    - Shower CNN: Val F1 0.979 @ thres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
    [19200530-065424.csv, 19700101-000012.csv, 19700101-000015.csv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]
2026-05-11 firmware: refactor trigger hierarchy + update CLAUDE.md
    AuraSync.ino (v3 → v4):
    - Replace raw gas_ohm P2 threshold with IAQ MLP (any mode, wakes SLEEP, queues during CD)
    - Restore P3 VOC inflection + PIR (accidentally removed in previous merge)
    - App spray now works in any mode incl. SLEEP (wakes system)
    - Fix stale trigger name p2_voc → iaq_poor in cooldown handler
    - Add DEMO_MODE flag with reduced IAQ_POOR_COUNT and SHOWER_CONSEC_MIN
    - Update header comment to reflect v4 trigger hierarchy and ML models
    CLAUDE.md:
    - Update status: ML Round 2 complete, models deployed
    - Correct IAQ model: MLP (64-32) not RF, Val F1 = 0.949
    - Mark all ML tasks as completed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
    [AuraSync.ino]
2026-05-11 Add week-06 devlog, fix week-03/05 status, update homepage credits
    - week-06.md / week-06.zh.md: new entry covering ML on-device inference
    (C weight array export, Round 2 Val F1 0.902), Firebase reverse control
    validation, Enclosure v2 cylindrical snap-fit, PCB v1 LPKF fabrication
    - week-05.md: status → Completed; tick shower, enclosure, PCB checkboxes
    - week-03.md / week-03.zh.md: status → Completed
    - strings.js: add Week 6 credits for both team members; update roles/bios
    - DevlogMarkdownBody.jsx: add enclosure-concept-embed and enclosure-printed-embed
    - Add PCB and enclosure images to public/images/devlog/
    [AuraSync_v2-B_Cu.gbr, AuraSync_v2-B_Mask.gbr, AuraSync_v2-B_Paste.gbr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]
2026-05-20 firmware: demo mode, WiFi/Firebase fixes, App sync improvements
    - DEMO_MODE enabled by default: BSEC_DECIMATE=1 (~3s/reading), 30s warmup,
    faster IAQ/CNN thresholds, 60s PIR/inflection windows for classroom demo
    - P3-inflection reworked: sticky latch (lastInflectionMs) so PIR can fire up
    to 60s after VOC inflection instead of needing to coincide within 5s
    - WiFi: 3-attempt retry with status printout; switched MAX_MODEM → MIN_MODEM
    to keep radio responsive for Firebase SSL
    - Firebase command polling: getString → getJSON to match App's JSON payload;
    deleteNode for acknowledgement instead of setString("")
    - Firebase secret: corrected 4th char '1' → 'l'
    - New pushSensorData(): writ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
    [App.js, AuraSync.ino]
2026-05-20 feat: week-07 devlog — AuraSync v4, Open House, App UI & enclosure casting
    - Add week-07.md and week-07.zh.md: firmware (DEMO_MODE, P3 latch,
    WiFi/Firebase fixes, pushSensorData, pollFirebaseSettings,
    feature_buffer fix), Open House demo, App UI polish, silicone mold
    lid casting with all 5 trigger paths verified
    - Mark week-06 as Completed (EN + ZH); restructure planned_next IDs
    to match week-07 prior_week_progress references
    - Add 8 new devlog images (silicone mold process, enclosure lid,
    app UI screenshots)
    - DevlogMarkdownBody: image centering, app-ui-update-embed and
    silicone-making-embed handlers
    - strings.js: Week 7 credits for Lucia and Yutong (EN + ZH)
    - App.js: trigger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
    [App.js]
2026-05-28 firmware: add PlatformIO project for AuraSync v4
    - PlatformIO project (pioarduino platform, IDF 5.x) replacing Arduino IDE
    - ESP-SR VAD + MultiNet7 voice commands: aura / spray / fragrance / release / stop
    - WS2812B 24-LED ring with state-reactive animations (sleep/awake/spray/cooldown/IAQ)
    - On-device IAQ MLP + Shower 1D-CNN inference
    - Firebase RTDB bidirectional sync, BME680 BSEC2 sensor integration
2026-06-02 feat: week-08 devlog — enclosure finishing, PCB bring-up, LED ring & full assembly
    - Add week-08.md: lower base SLA print + wet sanding, resin lid crack
    repair, custom PCB soldering, WS2812B 24-LED ring (5 state animations),
    PlatformIO migration, voice tuning ("Release" keyword), full assembly
    - Mark week-07.md as Completed; tick sand-cover, print-base, full-assembly
    checkboxes
    - DevlogMarkdownBody: add resin-repair-embed, led-ring-embed, assembly-embed
    handlers (placeholder images; user will supply photos)
    - strings.js: Week 8 credits for Lucia (LED firmware, PlatformIO, voice
    tuning) and Yutong (PCB soldering, enclosure finishing, lid repair)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
2026-06-02 feat: week-08 devlog — images, layout, ZH version & credit polish
    - week-08.md: add 10 photos (sanding, band saw, crack/repair stacked,
    finished base, final assembly solo, app control solo, IAQ+voice side-by-side);
    final-triggers-embed replaces assembly/tests embeds
    - week-08.zh.md: full Chinese mirror of week-08.md
    - week-07.md/zh.md: split pcb-video → pcb-soldering + backup-video (5 items),
    mark Completed, tick checkboxes
    - DevlogMarkdownBody.jsx: resin-repair/assembly handlers removed; new
    final-triggers-embed (poor-voc + voice, click-to-lightbox)
    - strings.js: compress Week 7-8 credits, standardize Devlog write-up,
    Full Assembly as own line; Lucia Week 8 adds Final presenta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
2026-06-02 fix: wider credit section, LED Firmware tag, backup-video partial, README rewrite
    - DevlogWeekPage: credits max-w-[52rem] → max-w-[68rem] to prevent tag wrapping
    - week-08 EN+ZH: 'WS2812B LED Firmware' → 'LED Firmware' credit tag
    - week-08 EN+ZH: backup-video false → "partial" (footage recorded, not edited)
    - README: full rewrite reflecting completed system — 5 trigger paths, LED ring,
    ML pipeline metrics, PlatformIO, mobile app, PCB specs
2026-06-02 feat: add 3D model files for AuraSync enclosure
    Fusion 360 source file and STL exports for all enclosure parts:
    inner body, lower body, upper body, and platform stand.
    [aurasync.f3z, inner body.stl, lower body.stl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]
